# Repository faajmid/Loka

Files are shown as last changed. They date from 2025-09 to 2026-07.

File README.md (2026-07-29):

# LokaBot

LokaBot is an open-source, palm-sized autonomous robot built around the **Microbots CodeCell C3**, a **DRV8833 dual motor driver**, and a **VL53L5CX-compatible multi-zone Time-of-Flight sensor**.

The project focuses on compact mechanical design, hardware integration, wiring, assembly, and practical robotics experiments. It includes detailed hardware documentation and Arduino examples for building, testing, and developing robotics applications.

<p align="center">
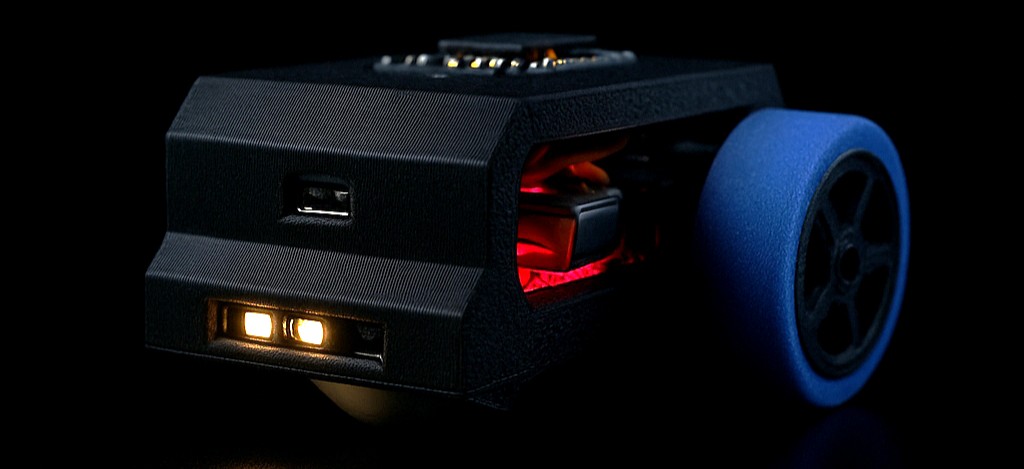
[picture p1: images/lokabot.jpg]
LokaBot
  
</p>

## LokaBot in action

### Obstacle avoidance

<p align="center">
  LokaBot obstacle avoidance
</p>

### Light and proximity sensing

<p align="center">
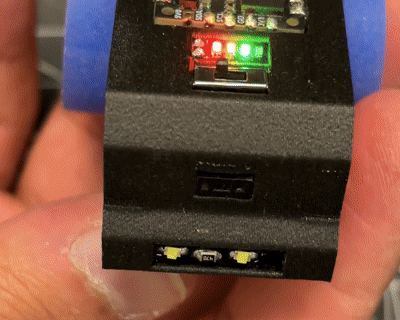
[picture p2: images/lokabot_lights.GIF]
LokaBot light and proximity sensing
  
</p>

### Motor movement

<p align="center">
  LokaBot motor movement
</p>

## Highlights

- 51 × 28 × 23 mm body, or approximately 51 × 54 × 23 mm with wheels
- CodeCell C3 with ESP32-C3, BNO085 IMU, VCNL4040 light/proximity sensor, USB-C, and LiPo charging
- 4×4 multi-zone ToF sensing using SparkFun's VL53L5CX Arduino library
- Two N10 3 V DC motors driven by a DRV8833
- Screw-free, press-fit 3D-printed body
- Silicone tires cast using a printable mold
- Three standalone Arduino examples based on maintained upstream libraries

## Repository structure

```text
Loka/
├── examples/
│   ├── 01_CodeCell_Sensors/
│   ├── 02_CodeCell_Motors/
│   └── 03_SparkFun_ToF/
├── hardware/
│   ├── 3D/
│   ├── images/
│   └── README.md
├── images/
├── ACKNOWLEDGEMENTS.md
├── LICENSE
└── README.md
```

## Hardware and assembly

The complete bill of materials, pin table, wiring diagram, printing notes, assembly guide, bring-up procedure, and safety notes are in [hardware/README.md](hardware/README.md).

## Required Arduino software

Install these using **Arduino IDE → Library Manager**:

1. **CodeCell** by Microbots
2. **SparkFun VL53L5CX Arduino Library** by SparkFun Electronics

Install **esp32 by Espressif Systems** using Boards Manager.

Recommended board settings for CodeCell C3:

- Board: `ESP32C3 Dev Module`
- USB CDC On Boot: `Enabled`
- CPU Frequency: `160 MHz`
- Flash Size: `4 MB (32 Mb)`
- Partition Scheme: `Minimal SPIFFS (1.9MB APP with OTA / 190KB SPIFFS)`

## Examples

### 1. CodeCell sensors

[`examples/01_CodeCell_Sensors/01_CodeCell_Sensors.ino`](examples/01_CodeCell_Sensors/01_CodeCell_Sensors.ino)

Uses the official CodeCell library to read the onboard light/proximity sensor, no-magnetometer rotation, gyroscope, accelerometer, tap detector, motion state, and battery level.

### 2. CodeCell motor control

[`examples/02_CodeCell_Motors/02_CodeCell_Motors.ino`](examples/02_CodeCell_Motors/02_CodeCell_Motors.ino)

Uses the official CodeCell GPIO/PWM API to control the external DRV8833 and both N10 motors through CodeCell pins IO1, IO2, IO5, and IO6.

### 3. SparkFun multi-zone ToF

[`examples/03_SparkFun_ToF/03_SparkFun_ToF.ino`](examples/03_SparkFun_ToF/03_SparkFun_ToF.ino)

Uses SparkFun's maintained VL53L5CX Arduino library to read and print a 4×4 distance frame. It also calculates left, centre, and right obstacle distances and prints a basic steering decision.

> **Compatibility note:** Verify that the physical Time-of-Flight module is VL53L5CX-compatible before uploading the example.

## First power-up checklist

1. Inspect for shorts and reversed battery polarity.
2. Power the CodeCell from USB without the motors connected.
3. Upload the CodeCell sensor example and verify Serial Monitor output.
4. Connect the ToF sensor and run the SparkFun ToF example.
5. Raise the robot so its wheels are clear of the table.
6. Connect the DRV8833 and motors, then run the motor example at low duty cycle.
7. Reverse a motor's two output wires if its physical direction is opposite to the expected direction.

## Project status

The mechanical design and hardware documentation are the primary deliverables. The three example sketches are hardware tests and starting points for navigation, obstacle avoidance, light following, and IMU-based behaviour.

## Acknowledgements

LokaBot uses and builds upon open-source work by Microbots, SparkFun Electronics, Espressif Systems, STMicroelectronics, and the wider Arduino community. See [ACKNOWLEDGEMENTS.md](ACKNOWLEDGEMENTS.md) for details.

## License

LokaBot's original project files and integration examples are released under the MIT License. Third-party libraries retain their original licenses and are installed separately rather than bundled into this repository.

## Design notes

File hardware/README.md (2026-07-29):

# LokaBot Hardware Guide

LokaBot is a compact two-wheel robot built around the **Microbots CodeCell C3**, an external **DRV8833 dual H-bridge**, two N10 motors, and a multi-zone Time-of-Flight sensor.

This repository focuses on the robot's mechanical design, hardware integration, wiring, and assembly. Software examples use maintained upstream Arduino libraries directly.

## Bill of materials

| Part | Specification | Qty | Notes |
|---|---|---:|---|
| Main controller | Microbots CodeCell C3 | 1 | ESP32-C3, BNO085 IMU, VCNL4040 light/proximity sensor, USB-C and LiPo charging |
| Multi-zone ToF board | VL53L5CX-compatible breakout | 1 | Required by the SparkFun VL53L5CX Arduino library used in the example |
| Motors | N10 DC motor, 3 V, approximately 298 RPM | 2 | 3 mm D-shaft |
| Motor driver | DRV8833 dual H-bridge | 1 | Drives both motors from four PWM-capable CodeCell pins |
| Battery | 1S 3.7 V LiPo, approximately 200–400 mAh | 1 | Select a protected cell that fits the body cavity |
| Switch | SS12D00G3 mini slide switch | 1 | Main battery isolation |
| Battery indicator | Compact 1S LED indicator | 1 | Approximately 5 × 9.5 mm |
| Front support | 10 mm perfume roller ball | 1 | Used as a small caster ball |
| Wire | 30 AWG flexible silicone wire | As required | Keep motor leads short |
| Printed parts | Body, wheel hubs and tire mold | — | Available in the [`3D`](3D) folder |
| Tire material | DoYB Mold Making A30 silicone, 1:1 mix | — | Used to cast soft tires |

> **Sensor compatibility:** Verify that the physical Time-of-Flight module is VL53L5CX-compatible before uploading the SparkFun example.

## Wiring

### CodeCell C3 to DRV8833

| CodeCell pin | DRV8833 pin | Function |
|---|---|---|
| IO1 | AIN1 | Left motor direction/PWM input 1 |
| IO2 | AIN2 | Left motor direction/PWM input 2 |
| IO5 | BIN1 | Right motor direction/PWM input 1 |
| IO6 | BIN2 | Right motor direction/PWM input 2 |
| VO | VM | Motor supply from the CodeCell power path |
| GD | GND | Common ground |

Connect the left motor to `AOUT1/AOUT2` and the right motor to `BOUT1/BOUT2`. If one wheel rotates in the wrong physical direction, swap that motor's two output wires.

### CodeCell C3 to multi-zone ToF board

| CodeCell pin | ToF pin | Function |
|---|---|---|
| 3V3 | VIN / VCC | 3.3 V sensor power |
| GD | GND | Common ground |
| SDA | SDA | I²C data |
| SCL | SCL | I²C clock |

The example uses the default `Wire` bus at 400 kHz. Keep SDA and SCL wires short.

### Wiring diagram

<p align="left">
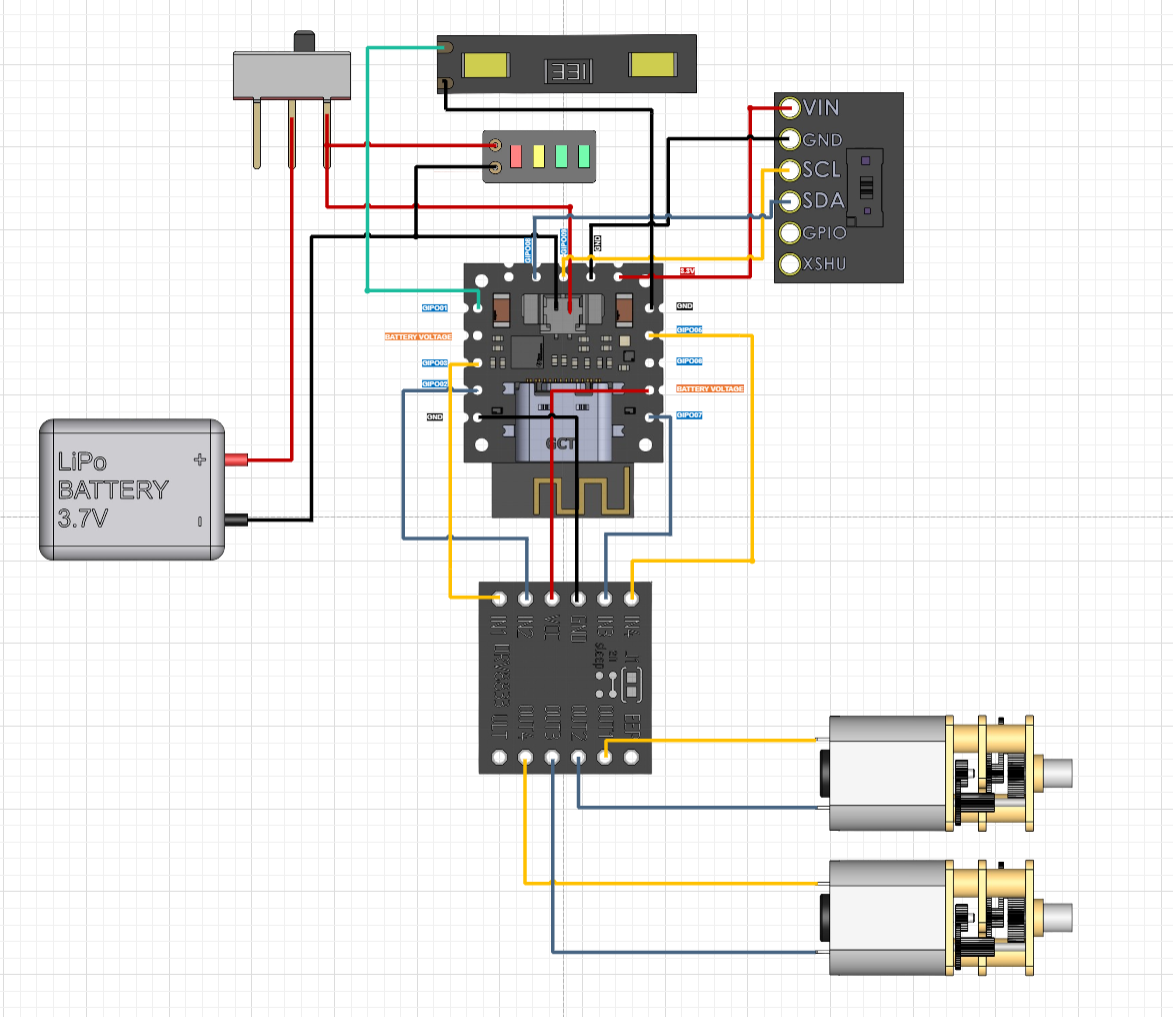
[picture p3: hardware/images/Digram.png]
LokaBot wiring diagram
  
</p>

## Arduino setup

Install using Arduino IDE Library Manager:

1. **CodeCell** by Microbots.
2. **SparkFun VL53L5CX Arduino Library** by SparkFun Electronics.

Install **esp32 by Espressif Systems** using Boards Manager.

Recommended CodeCell C3 settings:

- Board: `ESP32C3 Dev Module`
- USB CDC On Boot: `Enabled`
- CPU Frequency: `160 MHz`
- Flash Size: `4 MB (32 Mb)`
- Partition Scheme: `Minimal SPIFFS (1.9MB APP with OTA / 190KB SPIFFS)`

## Bring-up procedure

1. Inspect solder joints and confirm battery polarity.
2. Disconnect both motors from the DRV8833 outputs.
3. Power the CodeCell through USB.
4. Upload `01_CodeCell_Sensors.ino` and verify sensor and battery output.
5. Connect the ToF board and upload `03_SparkFun_ToF.ino`.
6. Confirm that the printed distance grid responds when an object moves in front of the robot.
7. Raise the robot so its wheels cannot touch the table.
8. Connect the motors and upload `02_CodeCell_Motors.ino`.
9. Confirm forward, reverse, left and right movement at the example's low duty cycle.
10. Install the battery and test again after confirming that USB operation is stable.

## Printing notes

- Recommended material: PLA or PLA-CF for the body and wheel hubs.
- The tire mold can be printed in standard PLA.
- Print the files as supplied.
- Enable supports for the body; tree supports are preferred.
- A layer height of 0.2 mm or finer is recommended.

Example slicer view:

<p align="left">
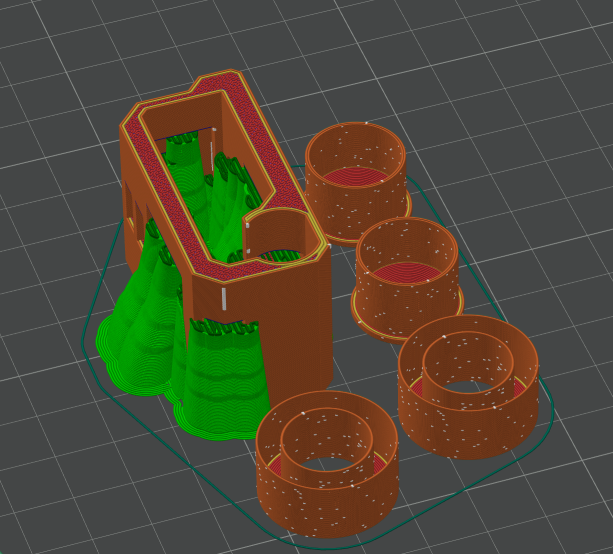
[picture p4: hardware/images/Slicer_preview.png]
LokaBot slicer preview
  
</p>

## Assembly

> Before assembly, carefully trim the screw-hole edges of the ToF breakout only when necessary for the intended press fit. Avoid damaging tracks or components.

1. Print all required `3mf` parts.
2. Test-fit the motors, CodeCell, motor driver and ToF board before soldering.
3. Route wires so they cannot touch the tires or motor shafts.
4. Press-fit the electronics and motors into the body.
5. Install the front roller ball.
6. Cast and install the silicone tires.
7. Verify that both wheels rotate freely before applying power.

## Casting silicone tires

Mix equal parts A and B silicone in a 1:1 ratio. Approximately 12 g of each part is sufficient for a pair, although the exact amount depends on waste and syringe size.

1. Measure equal quantities and mix thoroughly.

<p align="left">
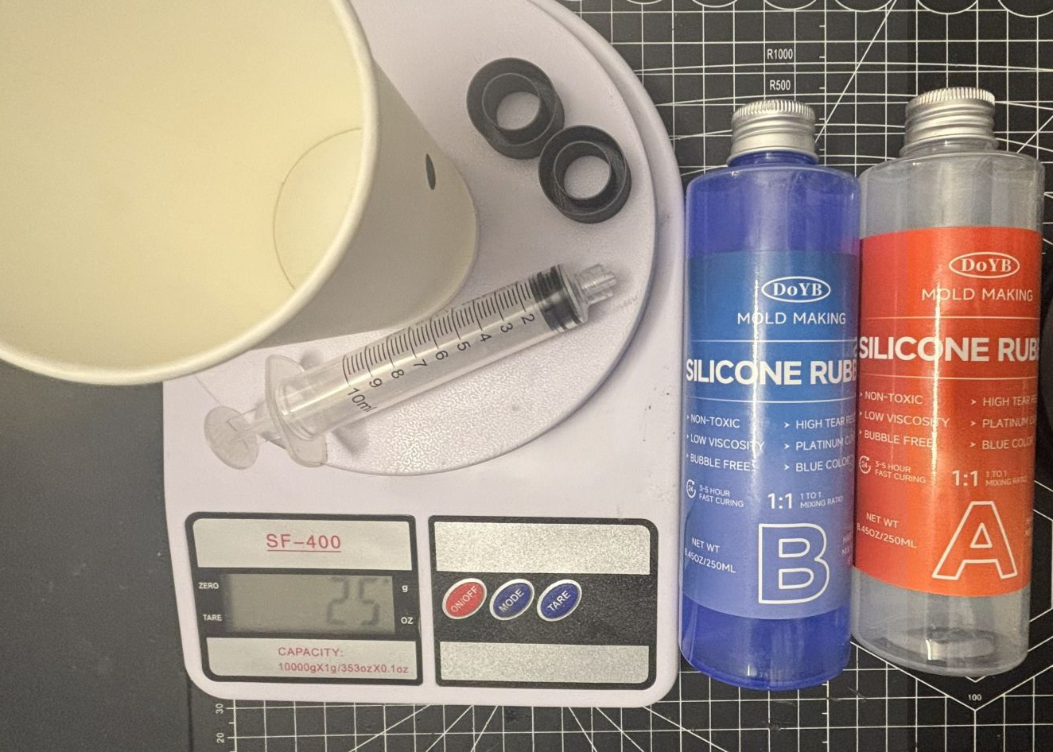
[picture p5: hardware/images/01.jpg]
Mixing tire silicone
  
</p>

2. Fill the mold carefully, preferably using a syringe, and allow it to cure for approximately four hours or according to the material manufacturer's instructions.

<p align="left">
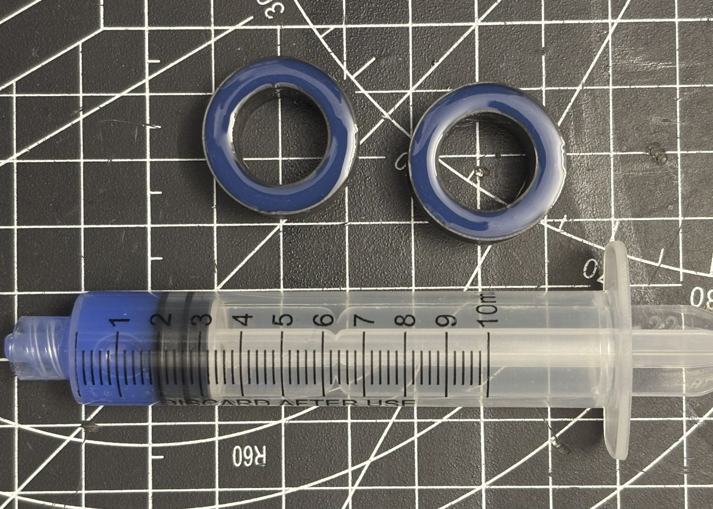
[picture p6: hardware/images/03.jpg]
Filling the LokaBot tire mold
  
</p>

3. Flex the mold gently to release the cured tire.

### Final result

<p align="left">
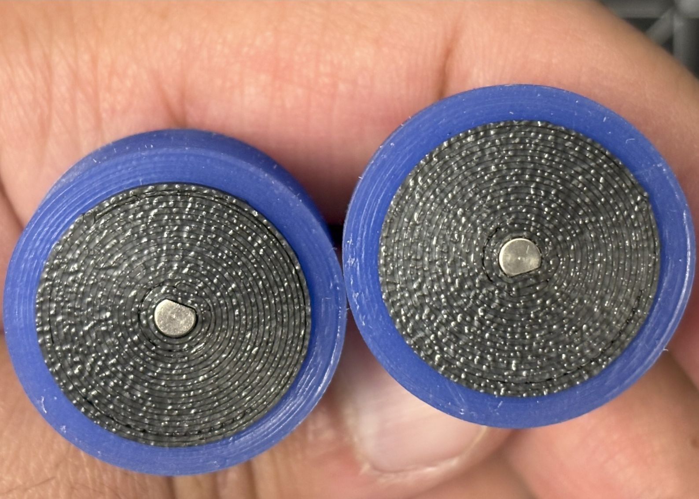
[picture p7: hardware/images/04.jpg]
Finished LokaBot silicone tire
  
</p>

<p align="left">
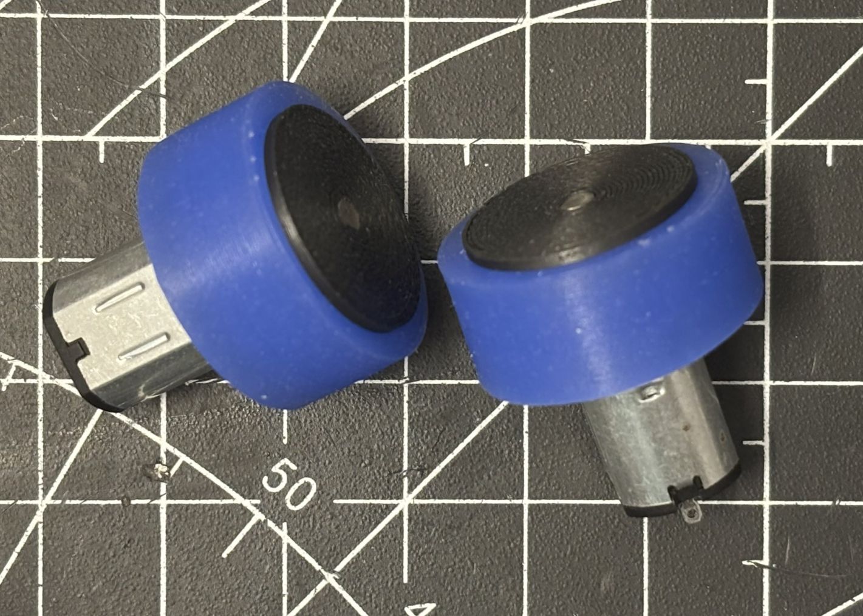
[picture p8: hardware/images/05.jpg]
LokaBot wheel and tire
  
</p>

## Safety notes

- Use only a correctly polarized 1S LiPo battery.
- Do not short, puncture or charge a damaged battery.
- Keep the robot attended while charging and during initial motor tests.
- Do not stall the motors for long periods.
- Disconnect power before changing wiring.

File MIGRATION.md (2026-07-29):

# Migration from the former Loka library

The repository has moved from a custom Arduino library to a hardware-first project.

## Removed legacy software

The former custom wrappers, bundled third-party driver sources, Arduino library metadata, and broken examples have been removed completely. The repository no longer contains a `src/` library tree.

Removed items include:

- `LokaBot.h`
- `LokaMCU.h/.cpp`
- `LokaMotors.h/.cpp`
- `LokaToF.h/.cpp`
- `src/library.properties`
- Bundled BNO085/SH-2 source files
- Bundled SparkFun/ST VL53L5CX source files
- Old `IMU`, `Light`, and `ToF` sketches that included `Loka.h`

## Replacement

Use the standalone examples in `examples/`:

1. `01_CodeCell_Sensors` — official CodeCell sensor and power API
2. `02_CodeCell_Motors` — official CodeCell GPIO/PWM API with the external DRV8833
3. `03_SparkFun_ToF` — official SparkFun VL53L5CX Arduino library

Install dependencies through Arduino Library Manager. Third-party libraries are no longer copied into or maintained inside the LokaBot repository.

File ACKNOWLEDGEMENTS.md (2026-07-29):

# Acknowledgements

LokaBot is possible because of the open-source hardware and software community.

## Microbots

The LokaBot controller is the **Microbots CodeCell C3**. The examples use the official **CodeCell Arduino Library**, including its sensor, GPIO/PWM, battery, power-management, and status functions.

- Project: CodeCell
- Maintainer: Microbots
- License: MIT
- Documentation: `https://microbots.io/pages/learn-codecell`
- Source: `https://github.com/microbotsio/CodeCell`

Thank you to the Microbots team for creating a compact controller that combines an ESP32-C3, BNO085 IMU, VCNL4040 light/proximity sensor, LiPo charging, and maker-friendly I/O.

## SparkFun Electronics

The multi-zone Time-of-Flight example is based on the official **SparkFun VL53L5CX Arduino Library** and its `Example1_DistanceArray` sketch by Nathan Seidle.

- Project: SparkFun VL53L5CX Arduino Library
- Maintainer: SparkFun Electronics
- Original example author: Nathan Seidle
- License: MIT
- Source: `https://github.com/sparkfun/SparkFun_VL53L5CX_Arduino_Library`

Thank you to SparkFun Electronics for maintaining accessible Arduino drivers and examples for robotics sensors.

## Other upstream contributors

CodeCell and the SparkFun ToF library incorporate or interface with work from additional organizations and contributors, including:

- Espressif Systems for the ESP32 Arduino core
- STMicroelectronics for the VL53L5CX sensor API and underlying driver technology
- CEVA and SparkFun contributors associated with BNO08x/BNO085 support
- The Arduino open-source community

All third-party projects retain their respective copyright notices and licenses. LokaBot does not claim ownership of those libraries. The libraries are installed separately through Arduino Library Manager and are not bundled as a custom Loka library.

## LokaBot project

LokaBot mechanical design, compact hardware integration, printed parts, wiring, assembly documentation, and robot-specific example adaptations were created by **Fahad Al Ajmi**.

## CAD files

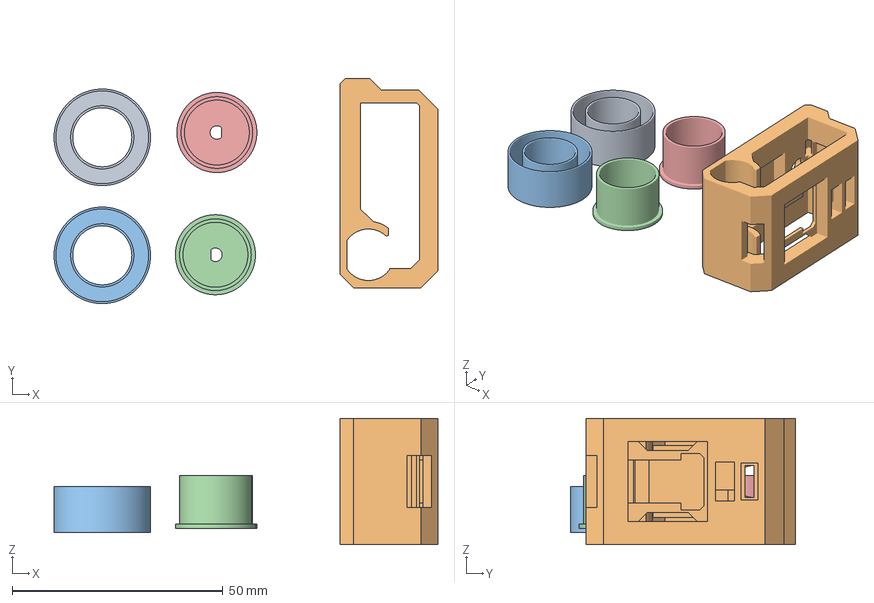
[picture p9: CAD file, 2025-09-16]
hardware/3D/LokaBot.3mf
91.1 x 53.4 x 30.0 mm
Tire_template
Base
Tire_template_(1)
Left_Wheel
Right_Wheel

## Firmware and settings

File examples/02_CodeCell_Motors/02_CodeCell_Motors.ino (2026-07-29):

/*
  LokaBot - DRV8833 dual motor test

  Uses the official CodeCell Arduino library by Microbots.
  LokaBot uses CodeCell pins IO1, IO2, IO5 and IO6 for the DRV8833.

  Raise the robot so the wheels are clear before the first test.
*/

#include <CodeCell.h>

CodeCell myCodeCell;

constexpr uint8_t LEFT_IN1  = 1; // CodeCell IO1 -> DRV8833 AIN1
constexpr uint8_t LEFT_IN2  = 2; // CodeCell IO2 -> DRV8833 AIN2
constexpr uint8_t RIGHT_IN1 = 5; // CodeCell IO5 -> DRV8833 BIN1
constexpr uint8_t RIGHT_IN2 = 6; // CodeCell IO6 -> DRV8833 BIN2

constexpr uint16_t PWM_FREQUENCY_HZ = 20000;

void setMotor(uint8_t in1, uint8_t in2, int speedPercent) {
  speedPercent = constrain(speedPercent, -100, 100);
  const uint8_t duty = abs(speedPercent);

  if (speedPercent > 0) {
    myCodeCell.pinPWM(in1, PWM_FREQUENCY_HZ, 0);
    myCodeCell.pinPWM(in2, PWM_FREQUENCY_HZ, duty);
  } else if (speedPercent < 0) {
    myCodeCell.pinPWM(in2, PWM_FREQUENCY_HZ, 0);
    myCodeCell.pinPWM(in1, PWM_FREQUENCY_HZ, duty);
  } else {
    myCodeCell.pinPWM(in1, PWM_FREQUENCY_HZ, 0);
    myCodeCell.pinPWM(in2, PWM_FREQUENCY_HZ, 0);
  }
}

void drive(int leftPercent, int rightPercent) {
  setMotor(LEFT_IN1, LEFT_IN2, leftPercent);
  setMotor(RIGHT_IN1, RIGHT_IN2, rightPercent);
}

void stopMotors() {
  drive(0, 0);
}

void runStep(const char *label, int left, int right, uint32_t durationMs) {
  Serial.println(label);
  drive(left, right);
  delay(durationMs);
  stopMotors();
  delay(500);
}

void setup() {
  Serial.begin(115200);
  delay(1000);

  // LIGHT is enabled so Init() uses a documented CodeCell configuration
  // while Run() continues power, battery and status-LED management.
  myCodeCell.Init(LIGHT);
  stopMotors();

  Serial.println("LokaBot motor test begins in 3 seconds");
  delay(3000);
}

void loop() {
  myCodeCell.Run(20);

  runStep("Forward", 35, 35, 1500);
  runStep("Reverse", -35, -35, 1500);
  runStep("Turn left", -30, 30, 1000);
  runStep("Turn right", 30, -30, 1000);

  Serial.println("Motor test complete. Restart the board to run again.");
  stopMotors();
  while (true) {
    myCodeCell.Run(10);
    delay(10);
  }
}

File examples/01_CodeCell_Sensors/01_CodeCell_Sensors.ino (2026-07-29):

/*
  LokaBot - CodeCell onboard sensors

  Uses the official CodeCell Arduino library by Microbots.
  Original library and documentation:
  https://github.com/microbotsio/CodeCell
  https://microbots.io/pages/learn-codecell

  The CodeCell library is MIT licensed. This LokaBot integration example
  keeps the upstream API visible instead of wrapping it in a custom library.
*/

#include <CodeCell.h>

CodeCell myCodeCell;

void setup() {
  Serial.begin(115200);
  delay(1000);

  myCodeCell.Init(
    LIGHT +
    MOTION_ROTATION_NO_MAG +
    MOTION_GYRO +
    MOTION_ACCELEROMETER +
    MOTION_STATE +
    MOTION_TAP_DETECTOR
  );

  Serial.println("LokaBot CodeCell sensor test");
}

void loop() {
  if (!myCodeCell.Run(20)) return;

  float roll = 0.0f, pitch = 0.0f, yaw = 0.0f;
  float gx = 0.0f, gy = 0.0f, gz = 0.0f;
  float ax = 0.0f, ay = 0.0f, az = 0.0f;

  myCodeCell.Motion_RotationNoMagRead(roll, pitch, yaw);
  myCodeCell.Motion_GyroRead(gx, gy, gz);
  myCodeCell.Motion_AccelerometerRead(ax, ay, az);

  const uint16_t proximity = myCodeCell.Light_ProximityRead();
  const uint16_t ambient = myCodeCell.Light_AmbientRead();
  const uint16_t white = myCodeCell.Light_WhiteRead();
  const uint8_t motionState = myCodeCell.Motion_StateRead();
  const bool tapped = myCodeCell.Motion_TapRead();
  const uint16_t battery = myCodeCell.BatteryLevelRead();

  Serial.print("Proximity: "); Serial.print(proximity);
  Serial.print(" | Ambient: "); Serial.print(ambient);
  Serial.print(" | White: "); Serial.print(white);

  Serial.print(" | RPY: ");
  Serial.print(roll, 1); Serial.print(", ");
  Serial.print(pitch, 1); Serial.print(", ");
  Serial.print(yaw, 1);

  Serial.print(" | Gyro: ");
  Serial.print(gx, 1); Serial.print(", ");
  Serial.print(gy, 1); Serial.print(", ");
  Serial.print(gz, 1);

  Serial.print(" | Accel: ");
  Serial.print(ax, 2); Serial.print(", ");
  Serial.print(ay, 2); Serial.print(", ");
  Serial.print(az, 2);

  Serial.print(" | Motion state: "); Serial.print(motionState);
  Serial.print(" | Battery: ");

  if (battery <= 100) {
    Serial.print(battery);
    Serial.print('%');
  } else if (battery == 101) {
    Serial.print("Charging");
  } else if (battery == 102) {
    Serial.print("USB power");
  }

  if (tapped) Serial.print(" | TAP");
  Serial.println();
}

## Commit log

2025-09-05 Add Loka.h core header
    Created the main Loka.h file that includes IMU (BNO085), Light (VCNL4040), Tap, and ToF (VL53L7CX). Motors remain work in progress and are excluded for now.
2025-09-05 Add LokaMCU core files
    Added LokaMCU.h and LokaMCU.cpp:
    - Handles IMU BNO085 rotation & gyro
    - Light sensor VCNL4040 and tap detection
    - Flexible, orderless calls with clean printing
2025-09-05 Add LokaMCU.cpp implementation
    - Implements IMU BNO085 rotation & gyro functions
    - Light sensor VCNL4040 ambient/proximity reads
    - Tap detection logic
    - Clean printer functions that mirror user calls
2025-09-05 Add Loka.h core header
    - Main entry point for the Loka library
    - Includes IMU BNO085, Light (VCNL4040), and ToF VL53L7CX modules
    - Motors are marked as WIP and excluded by default
    - Provides a clean structure so users can include just <Loka.h> in their sketches
2025-09-05 Add LokaToF.cpp implementation
    - Implements ToF distance sensor functions
    - Handles zone grid printing with correct orientation (SparkFun style, zone 0 = top-right)
    - Supports custom zone groupings and averages
    - Provides helper for LeftAvg – RightAvg as Error() for PD steering
2025-09-05 Add mcu drivers BNO085 CEVA SH2 + SHTP
2025-09-05 Add mcu driver files BNO085, SH2, SHTP
2025-09-05 Add tof driver files VL53L7CX + SparkFun wrapper
2025-09-05 Add IMU example rotation, gyro, tap detection
    Demonstrates using the onboard BNO085 IMU with flexible Rot/Gyro reads, tap detection,
    and clean PrintIMU output.
2025-09-05 Add Light example ambient & proximity
    Shows how to use the VCNL4040 light sensor with flexible Light() calls,
    automatic headlight control, and PrintLight output.
2025-09-05 Add ToF example VL53L7CX 16/64 zone distance
    Demonstrates VL53L7CX ToF sensor in 16-zone and 64-zone modes, with zone grid printing, Left/Middle/Right grouping, and averages.
2025-09-09 Update and rename Loka.step to LokaBot.step
    [LokaBot.step]
2025-09-20 Add motors control and simplify VL53L7CX API
    - New: LokaMotors (DC motor control: Init(), Ctrl(-100..100))
    - ToF: Datasheet zone layout; Zones() and Zones(i,...) selection
    - Defaults: Z16 ~30 Hz, Z64 ~15 Hz; PrintZones auto-fetches frames
    - Examples: added Motors and ToF quick starts
2026-02-12 Update README with supported sensors information
2026-07-29 Refocus LokaBot on hardware and official Arduino libraries
    Replace the broken custom Arduino wrapper with hardware-first documentation and three standalone examples using the official CodeCell and SparkFun libraries.
    [01_CodeCell_Sensors.ino, 02_CodeCell_Motors.ino, 03_SparkFun_ToF.ino]
2026-07-29 Remove unused vendored ToF driver
